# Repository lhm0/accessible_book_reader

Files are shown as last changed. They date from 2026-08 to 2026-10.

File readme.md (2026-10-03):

# Accessible Book Reader

## update October 3rd, 2026

The design files (`.f3z` / `.f3d`) and corresponding STL files for `front`,
`front2`, `back`, `back2`, and their `_dev` variants have been updated to
correct a design error.

The `camera_block` has also been redesigned for easier, higher-quality
printing. It now consists of two parts joined with a single screw.

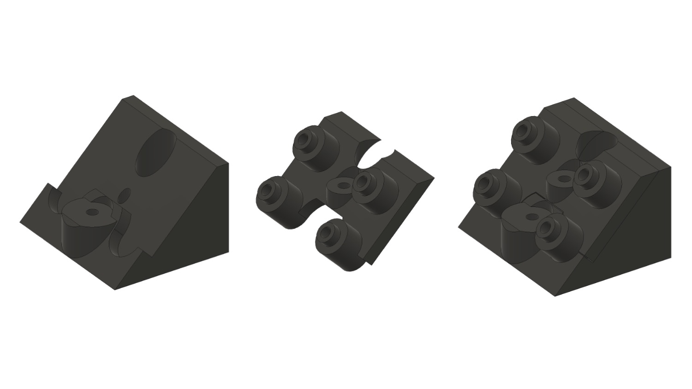
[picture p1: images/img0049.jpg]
Updated two-part camera block


## Project overview

**Listen to printed books – and catch up on the story at the press of a button.**

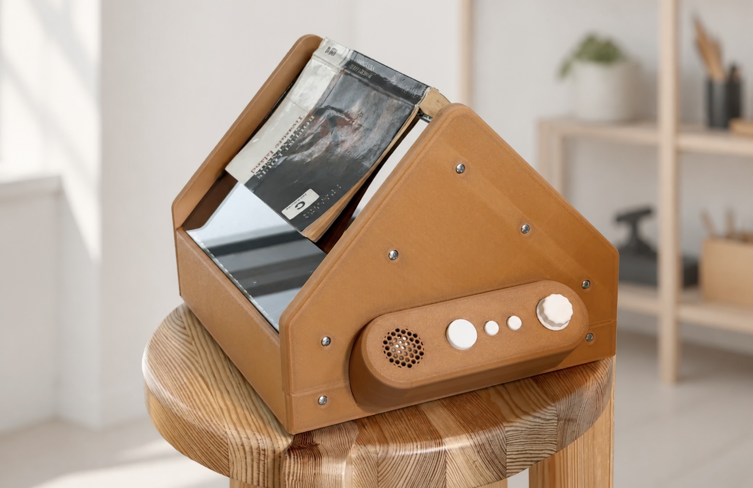
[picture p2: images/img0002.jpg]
Accessible Book Reader with a book in place, a speaker, three buttons and a volume knob


The **Accessible Book Reader (ABR)** is a reading device built around the
Raspberry Pi 5. It aims to make books more accessible to people who find
printed text difficult to read. Place an open book on the device, press a
button and listen: two cameras capture the spread, the device recognises
the text and reads both pages aloud in order. A sound signals when it is
time to turn the page by hand.

After a break, ABR can help you find your place in the story. At the press
of a button, it summarises the most recently captured sections or the book
so far. NFC tags identify each book and link it to its saved text and
summaries. Three buttons, a volume knob and spoken prompts provide the
on-device controls.

ABR combines a custom enclosure and electronics with open-source software.
This repository contains the code, circuit schematics, mechanical design
files and documentation for building and improving the device. Book-language
profiles for German and U.S. English are integrated. Text recognition runs
locally on the Raspberry Pi; the current speech and AI summary features use
Google Cloud services and require an internet connection and a configured
cloud account.

The physical device has been tested and is under active development.
Current work focuses on long-term testing and refining summaries.
Book identification currently uses a modified PN5180 NFC reader breakout
board; the setup is documented in this repository. A custom NFC reader is
also being developed to make the hardware easier to reproduce.
Feedback from users, build experiences and contributions are welcome.

[Deutsche Dokumentation](readme_DE.md) ·
[Installation](#installation) ·
[Hardware](hardware/README.md) ·
[Contributing](CONTRIBUTING.md) ·
[Licence](#licence)

## Development status

The project has progressed beyond a basic OCR/TTS prototype:

- the real capture path with two Raspberry Pi cameras has been verified
- `RapidOCR` runs reliably on the Raspberry Pi
- `Google Cloud TTS` is integrated
- the control panel, NFC book context, page storage, and automatic reading are implemented
- remote file maintenance by e-mail is implemented
- multiple saved Wi-Fi profiles can be selected automatically or switched explicitly
- central German and U.S. English book-language profiles control runtime TTS,
  chapter announcements, and RapidOCR model selection; German remains the
  backwards-compatible default
- new NFC books store their language permanently in `book.json`; OCR, ingest,
  chapter assembly, summaries, and TTS reject mixed-language book data

Current development focuses on:

- stabilising and refining the section and summary layer
- long-term testing of the integrated dual-reader PN5180 path with
  `ISO14443A` and `ISO15693`

## Current production path

The preferred real-world setup on a Raspberry Pi 5 is:

- runtime: `hardware/control_panel_service.py`
- page TTS: `Google Cloud TTS`, using the voice from the active language profile
- system messages: pre-generated WAV files from the active language folder
  (`system_audio/messages/de/` or `system_audio/messages/en/`)
- book identification: PN5180 gateway over UART
- audio hardware: MAX98357A over I2S; the system-wide ALSA `default` device
  must address this card by its symbolic card name

The runtime currently behaves as follows:

- PN5180 polling starts immediately with `STATUS_START`
- both photographs are captured before `STATUS_FETCH` retrieves the book identity;
  NFC reader position is no longer used for page orientation
- an `ISO14443A` tag remains the preferred book key; a simultaneously detected
  `ISO15693` tag is stored as an alternative identifier, while a new book can
  also be created directly from a single `ISO15693` tag
- before the normal page OCR, RapidOCR detects three long text lines in the
  prepared left image and classifies them as upright or upside down
- an upside-down result swaps `case/left.jpg` and `case/right.jpg`
- each reliable result updates `library/<TAG_ID>/state/page_orientation.json`;
  text-poor or empty pages use that stored value instead of aborting
- `case/right.jpg` is then rotated by 180 degrees exactly once; OCR
  preprocessing performs no additional fixed page rotation
- both pages are captured completely before processing begins
- the left page is processed before the right page
- image preparation, OCR, `PageIngestor`, and TTS initially run only for the left page
- while the left page is already playing, the right page proceeds through
  image preparation, OCR, `PageIngestor`, and TTS
- after the right page has played completely, the language-specific
  `tatata.wav` signals that the user should turn the page; cancellation or an
  audio/TTS error suppresses this signal

## Implemented features

### Device runtime

- long-running front-panel monitor
- `Start / Stop / NFC` triggers the real
  `capture -> image preparation -> OCR -> page-ingest` path
- heartbeat while waiting for the first page audio
- interruptible page playback
- turn-page signal only after successful completion of the complete spread;
  it is not played when page audio is cancelled
- EC11 edge-interrupt volume control with a thread-safe target value; it also
  applies block by block while `bing.wav` or page audio is playing
- book-deletion dialogue using the three-button chord and the EC11 push button
- persistent per-book usage statistics for scanned pages, reading time, and
  both summary functions; daily e-mail reports cover 04:00 to 04:00, including
  days without device use

### Book and page data

- one directory per book under `library/<TAG_ID>/`
- alternative ISO15693 mappings under
  `library/<ISO14443A_TAG_ID>/iso15693_tag_ids.txt`
- persistent OCR orientation fallback under
  `library/<TAG_ID>/state/page_orientation.json`
- `BookStore`
- `PageIngestor`
- `ChapterAssembler` for 10-to-20-page sections with mid-page boundaries
- `SummaryManager` for Gemini section and whole-book summaries
- one `PageRecord` per page
- one `ChapterRecord` per section
- one `ScanRecord` per double-page scan
- automatic page playback based on `speak_text`

### Text cases handled explicitly

- a missing page number on only one side of an otherwise complete double-page
  report; provisional `page_1.json`/`page_2.json` files are replaced with the
  inferred four-digit filenames after the second page is available
- multiple chapter markers on one page
- heading-only pages such as `INTERMEZZO`
- incomplete sentence fragments across pages
- hyphenation across lines and across the left/right page boundary
- letter-spaced words such as `U E B E R S C H R I F T` are spoken without the spacing
- short all-uppercase headings are made readable in `speak_text` and marked as separate paragraphs
- German spoken text replaces `Dr.` with `Doktor` and `Notre-Dame` with
  `Notre Damm`; the source-faithful `clean_text` remains unchanged (stored
  pages receive these replacements only after another page ingest)
- short parenthesised OCR artefacts containing digits are not carried over as
  sentence fragments to the next page
- chapter announcements use cardinal numbers, for example `Kapitel zwei`
- clear SSML pauses before and after chapter announcements

Current sentence-fragment behaviour:

- the right-page tail fragment is also kept in
  `library/<TAG_ID>/state/pending_right_tail_fragment.json`
- without a page number, no fragment from an earlier scan is prepended;
  pending state is never a substitute for a known predecessor
- inconsistent numbering in a complete spread also blocks carryover and is
  persisted as `metadata.page_number_sequence_valid=false`, preventing those
  pages from becoming fragment sources for later scans
- known numbering gives priority to the stored right page with the
  exact preceding number. Successfully renumbered opening pages qualify again
- if the numbered predecessor is entirely absent, a complete, consecutively
  numbered spread may use the fragment from `pages/page_2.json`, provided it
  is an unnumbered right page from another scan. An existing predecessor with
  no fragment does not trigger this fallback. Single-page reports and unclear
  current numbering cannot use it either
- during incremental processing, playback of the numbered left page waits
  for the right page in this special case. Both pages are then played after
  checking the full spread; inconsistent numbering omits the external fragment
- if that placeholder is subsequently renumbered automatically, its fragment
  is not prepended a second time
- left-to-right carryover within the same capture remains intact because
  physical adjacency is known even without page numbers
- plausible but factually wrong OCR numbers cannot be identified by this
  numbering check alone. Existing stored spoken text is not cleaned retroactively

### Recovering an unnumbered opening spread

After storing a complete spread with consecutive page numbers, the ingestor
checks for both unnumbered `pages/page_1.json` and `pages/page_2.json`. If both
immediately preceding page slots are free, these placeholders receive those
numbers. For example, ingesting pages 7/8 renames the placeholders to
`0005.json` / `0006.json`, with internal IDs `page_0005` / `page_0006`.

The placeholders must be the left/right pages of the same earlier scan.
Single-page reports, nonconsecutive numbers, already numbered placeholders,
or either occupied destination prevent repair. Existing numbered pages are
never overwritten. Repair runs during ingest, not just on service startup.

The correction updates scan manifests, chapter page lists and ranges, chapter
boundaries including `next_start_boundary`, assembler state, and structured
page references in state and summary files. Chapter summary ranges are updated;
summary prose is not regenerated. Source OCR reports, `metadata.report_page_id`,
scan identity and page text are preserved. A tail fragment from the repaired
right page is carried into the current spoken text when applicable.

Repaired pages have `metadata.page_number_inferred=true`,
`page_number_inference="following_spread"`, and the triggering scan ID in
`page_number_inference_scan_id`. The service logs
`Vorherige Doppelseite nachnummeriert: left:5, right:6; gespeicherte Referenzen aktualisiert.`

## Section and summary layer

- sections are assembled from existing `PageRecord` objects after every ingest
- a section ends at the first detected chapter boundary within a 10-to-20-page window
- without a chapter marker, a section ends at the last complete paragraph on
  page 20 and the following boundary is stored persistently
- completed sections are stored under `library/<TAG_ID>/chapters/`
- Gemini creates a section summary when a new section is completed
- the chapter/last-pages summary button speaks the latest section summary,
  creates or refreshes it when needed, and provides an intro plus `bing` heartbeat
- if open text exists after the last completed section, the same action
  combines it with the stored summary into a temporary current recap; this is
  spoken but not stored
- before the first completed section, the available open text is summarised temporarily
- the whole-book summary button creates and speaks a current “previously in
  this book” recap in chapter order, also with an intro and `bing` heartbeat
- if no summary is available, the runtime plays `keine_zusammenfassung`

## Installation

This README is the entry point for a new installation. Detailed hardware setup
and the final verification checklist are covered by
[docs/RASPBERRY_PI_SETUP.md](docs/RASPBERRY_PI_SETUP.md).

### 1. Prepare the Raspberry Pi and clone the repository

Raspberry Pi OS Lite (64-bit) is recommended. After the first boot, update the
system and install the required packages:

```bash
sudo apt update
sudo apt full-upgrade -y
sudo apt install -y \
  git curl ca-certificates \
  build-essential pkg-config \
  python3 python3-venv python3-pip python3-dev \
  tesseract-ocr tesseract-ocr-deu \
  libgl1 libopenblas-dev \
  espeak-ng alsa-utils pulseaudio-utils \
  htop tmux

mkdir -p ~/src
git clone https://github.com/lhm0/accessible_book_reader.git ~/src/abr
cd ~/src/abr
```

The cameras, header UART, and MAX98357A additionally require the entries in
`/boot/firmware/config.txt` and `/etc/asound.conf` described in the Raspberry
Pi setup guide. The repository's `config.txt` is a reference for the verified
hardware and must not blindly replace an existing boot configuration. Reboot,
then verify the cameras, UART, and audio as documented.

Firmware and wiring for the preferred PN5180 gateway are documented in
[hardware/pn5180_gateway/README.md](hardware/pn5180_gateway/README.md). The
alternative PN532 path is documented in
[hardware/pn532_gateway/README.md](hardware/pn532_gateway/README.md).

### 2. Install the Python environment

Create a fresh environment with the normal `python3`, not PlatformIO's Python,
and do not copy a virtual environment from another computer:

```bash
cd ~/src/abr
python3 -m venv .venv
source .venv/bin/activate
python -m pip install --upgrade pip
python -m pip install -e ".[ocr-rapidocr,dev,tts-google]"
```

Optional OCR backends:

```bash
pip install ".[ocr-tesseract]"
pip install ".[ocr-paddle]"
```

### 3. Configure Google Cloud for TTS and summaries

The production service requires Application Default Credentials (`ADC`) for a
Google Cloud project with billing and the required APIs enabled. After
installing the Google Cloud CLI for Raspberry Pi OS:

```bash
gcloud services enable \
  texttospeech.googleapis.com \
  aiplatform.googleapis.com \
  --project YOUR_PROJECT_ID
gcloud auth application-default login
gcloud auth application-default set-quota-project YOUR_PROJECT_ID
gcloud config set project YOUR_PROJECT_ID
```

These commands store credentials outside the repository under
`~/.config/gcloud/`. Never copy credential files into the project. The systemd
installer sets `HOME` to the installing user's home directory so that the
service finds the same ADC data. A service account may alternatively be
provided through Google's documented ADC mechanism. See the Raspberry Pi
setup guide for details and test commands.

### 4. Configure the device and install services

Run installers from the repository with `sudo`. They derive the user, home
directory, repository location, and `.venv` from the current installation; no
fixed username or absolute project path is required.

```bash
cd ~/src/abr
sudo deploy/install_language_switch.sh
sudo deploy/install_control_panel_service.sh
```

This creates `~/.config/abr/device.json` with German as the default when the
file is missing and installs the production service. Select the book language
with `sudo abr-language de` or `sudo abr-language en`. See
[docs/LANGUAGE_PROFILES.md](docs/LANGUAGE_PROFILES.md).

Optional features:

```bash
# Install continuous recovery across saved Wi-Fi profiles
sudo deploy/install_wifi_autoconnect.sh

# First run: create mail.ini; edit it, then run the installer again
sudo deploy/install_remote_mail.sh
sudo deploy/install_remote_mail.sh

# Install only after mail.ini has been configured
sudo deploy/install_usage_statistics.sh
```

Wi-Fi credentials remain in NetworkManager. Add profiles interactively using
the commands in [docs/WIFI_PROFILES.md](docs/WIFI_PROFILES.md). E-mail setup is
described below and in
[docs/REMOTE_MAINTENANCE_EMAIL.md](docs/REMOTE_MAINTENANCE_EMAIL.md).

### Local and generated configuration files

| Path | Purpose and creation | Tracked? |
|---|---|---|
| `/boot/firmware/config.txt` | Camera, UART, and I2S configuration; edit according to the Pi setup guide | No |
| `/etc/asound.conf` | ALSA default for MAX98357A; edit according to the Pi setup guide | No |
| `~/.config/gcloud/` | Google ADC and quota project; generated by `gcloud` or a service-account setup | No |
| `~/.config/abr/device.json` | Book language; generated by `install_language_switch.sh` | No |
| `~/.config/abr/mail.ini` | Mail account and recipient; neutral template generated by `install_remote_mail.sh` | No |
| NetworkManager profiles | SSIDs and Wi-Fi passwords; created interactively with `abr.wifi_profiles` | No |
| `/etc/systemd/system/abr-*.service` and `abr-*.timer` | Local user and project paths; generated by the relevant service installers | No |
| `calibration/out/cam0_planar.npz`, `cam1_planar.npz` | Included reference calibration; regenerate for different camera mechanics | Yes |

No `.env` file is required. Optional experimental backends read
`OPENAI_API_KEY` or `ELEVENLABS_API_KEY` only from the local process
environment. The production Google path uses ADC.

### 5. Verify the installation

```bash
cd ~/src/abr
source .venv/bin/activate
python -m pytest -q
systemctl status abr-control-panel.service --no-pager -l
journalctl -u abr-control-panel.service -n 100 --no-pager
```

Then complete the hardware and runtime verification in
[docs/RASPBERRY_PI_SETUP.md](docs/RASPBERRY_PI_SETUP.md).

### Local e-mail configuration

Personal addresses, usernames, and passwords are not stored in the
repository. Mail features read `~/.config/abr/mail.ini` on the Raspberry Pi.
The first invocation of `sudo deploy/install_remote_mail.sh` creates a template
with mode `0600`. Edit the local file:

```ini
[mail]
address = abr-device@example.com
recipient = owner@example.com
username = abr-device@example.com
password = MAIL_APP_PASSWORD
smtp_host = smtp.example.com
smtp_port = 465
imap_host = imap.example.com
imap_port = 993
inbox = INBOX
```

`address` and `username` identify the device account. Remote-maintenance files
and usage reports are sent to `recipient`, and uploads are accepted only from
that exact sender. Real values remain exclusively in this local, untracked
file. For backwards compatibility, installations without `recipient` use the
value of `address`.

Important operational notes:

- `rapidocr` and `onnxruntime` are required for the primary OCR path
- Tesseract remains a fallback and comparison backend
- PaddleOCR is currently not a reliable production path on Raspberry Pi
- automatic summaries use the same Google Cloud credentials as TTS
- `target-pages` is converted at 250 words per text page; `0.5` therefore
  targets 125 words
- Gemini receives a generous technical token budget so internal thinking
  tokens do not truncate the visible answer prematurely
- if the first answer exceeds the word limit by more than ten percent, a
  separate shortening pass is performed
- only a response not terminated by the token limit is stored with
  `generation_complete=true`; legacy summaries without this marker are
  regenerated once on their next use
- `/etc/asound.conf` must expose a `plug` PCM named `default` for
  `hw:CARD=MAX98357A,DEV=0`; otherwise `aplay` may open HDMI and fail with
  `Unknown error 524`

## Quick start

### Manual capture and OCR reference run

```bash
cd ~/src/abr
source .venv/bin/activate
python hardware/capture_double_page.py --no-denoise
python hardware/run_rapidocr.py \
  --ocr-dir captures/latest/ocr \
  --output-dir runs/latest_rapidocr \
  --orientation-mode off \
  --overlay
```

### Full runtime service on the Raspberry Pi

The runtime may be started directly for short manual tests. Continuous
operation uses the SSH-independent `abr-control-panel.service`; installation,
logs, restart testing, and troubleshooting are documented in
[docs/SYSTEMD_CONTROL_PANEL_SERVICE.md](docs/SYSTEMD_CONTROL_PANEL_SERVICE.md).

```bash
cd ~/src/abr
source .venv/bin/activate
python hardware/control_panel_service.py \
  --gpio-backend auto \
  --job-mode capture-ocr \
  --library-root library \
  --nfc-mode gateway \
  --page-tts-speed 0.85 \
  --chapter-summary-target-pages 1.5 \
  --book-summary-target-pages 1.5
```

### Separate Neural2-H test

The production Google path remains unchanged: backend `google`, voice
`de-DE-Standard-H`, and still the default when no additional option is given.
Neural2-H is an isolated opt-in path:

```bash
python hardware/control_panel_service.py \
  --gpio-backend auto \
  --job-mode capture-ocr \
  --library-root library \
  --nfc-mode gateway \
  --page-tts-backend google-neural2 \
  --page-tts-speed 0.85
```

Return to the production path with `--page-tts-backend google` or omit the
option. `--google-neural2-voice-name` selects a different Neural2 voice; the
default is `de-DE-Neural2-H`.

### Standard-H with enhanced SSML preparation

The optional `google-standard-enhanced` path still uses `de-DE-Standard-H` and
the same Google Cloud TTS backend. Only text preparation differs: paragraphs
and sentences are structured, chapters retain their long pause, and short
headings are moderately emphasised and separated from following text. For
questions, the complete final word is experimentally raised by `+3st`. The
renderer verifies that no spoken words were changed and falls back to the
original SSML preparation if validation fails.

Sentences inside a paragraph receive a `900ms` pause. The last sentence of a
paragraph receives `2000ms` instead; pauses are not added together. Paragraph
boundaries come from OCR `layout_blocks` and are stored as blank lines in
`speak_text`. For already stored pages, a simple line break after `.` or `?`
also acts as a fallback paragraph boundary, including a directly following
closing quotation mark. If a fully quoted dialogue sentence in `"..."`,
`»...«`, or `„...“` is followed by a paragraph break, that boundary is spoken
like a normal sentence boundary: `900ms` instead of `2000ms`. Stored paragraph
data is not changed.

Enable the path with:

```bash
python hardware/control_panel_service.py \
  --gpio-backend auto \
  --job-mode capture-ocr \
  --library-root library \
  --nfc-mode gateway \
  --page-tts-backend google-standard-enhanced \
  --page-tts-speed 0.9
```

The unchanged Standard-H path remains available through
`--page-tts-backend google` or by omitting the option.

### Page direction and repeated-page checks

The runtime stores, per book, the page numbers of the most recently accepted
double-page scan:

- if a new scan overlaps those page numbers, it plays
  `system_audio/messages/<language>/repeat_page.wav` and cancels page playback
- if the smallest new page number is below the smallest previously read page,
  it plays `system_audio/messages/<language>/wrong_direction.wav` and cancels playback
- the immediately following scan may pass the condition once; the relevant
  override marker is then cleared
- if the right-side partial result arrives after a warning from the same scan,
  it is not played either
- scans without detected page numbers bypass these two checks

Markers and last-read pages are maintained per book and removed when the book
is deleted. These warnings play directly in the ingest path rather than via
the general asynchronous system-audio queue. The runtime logs their start and
successful completion and reports a missing WAV path explicitly. In the
incremental capture path, the runner waits for the left ingest result; if it
triggers a warning, the foreground job stops before right-side preparation and
OCR. After the warning, the normal `CANCELLED` event returns the runtime to
`IDLE`.

### Long summaries

Before Google TTS, chapter and whole-book summaries are split at complete
sentences when the rendered input would otherwise be too large. Summary chunks
are limited to 900 bytes including SSML; the general Google safety limit is
3800 bytes. Chunks use the same audio queue and play in order, with labels such
as `1/N` and `2/N`. Short summaries remain a single TTS request.

The pre-generated summary announcement and first `bing` play synchronously
before the summary job. Pending heartbeat sounds are discarded after summary
audio is activated, preventing a late `bing` after the summary.

The validity of `book_so_far_summary.json` includes a SHA-256 fingerprint of
the content and modification time of every chapter summary. A previous short
book summary is regenerated when its sources change. Legacy files without a
fingerprint are refreshed once on their next use.

Chapter and book summaries follow the active language profile. German uses
German prompts; English uses U.S. English prompts. Persistent summary files
store `metadata.language`. A cache in another language is regenerated, while
legacy cache files without a language field are treated as German.

### Separate Gemini 2.5 Flash TTS test

Gemini TTS is another isolated opt-in path:

```bash
python hardware/control_panel_service.py \
  --gpio-backend auto \
  --job-mode capture-ocr \
  --library-root library \
  --nfc-mode gateway \
  --page-tts-backend google-gemini-flash \
  --page-tts-speed 0.85
```

Defaults for this experimental path:

- model `gemini-2.5-flash-tts`
- voice `Charon`
- a dedicated German audiobook prompt
- plain-text rather than SSML input; the prompt controls pauses and delivery

Optional overrides:

```bash
--google-gemini-flash-voice-name Charon
--google-gemini-flash-prompt "Lies ruhig und natuerlich wie ein Hoerbuchsprecher."
```

Google limits both Gemini TTS text and prompt to 4000 bytes. The backend checks
this limit and reports a clear error instead of silently truncating input.
Return to the production path with `--page-tts-backend google` or omit the
option.

### Offline ingest of an existing OCR report

```bash
cd ~/src/abr
source .venv/bin/activate
python hardware/page_ingest_debug.py \
  --library-root library \
  --book-tag-id TESTBOOK \
  --report-path captures/scan_xxx/ocr_text/report.json
```

## Generate system messages

Tool: [hardware/generate_audio_message.py](hardware/generate_audio_message.py)

```bash
python hardware/generate_audio_message.py \
  --ssml \
  --output-root ~/tmp_audio_export/de \
  fehler \
  '<speak>Fehler.<break time="700ms"/>Bitte erneut versuchen.</speak>'
```

Generate new messages outside the repository on the Raspberry Pi. Copy them
to the Mac afterwards and only then place them in the relevant
`system_audio/messages/de/` or `system_audio/messages/en/` directory.

## Important documentation

- [German README](readme_DE.md)
- [docs/LANGUAGE_PROFILES.md](docs/LANGUAGE_PROFILES.md)
- [docs/CONTROL_RUNTIME_ARCHITECTURE.md](docs/CONTROL_RUNTIME_ARCHITECTURE.md)
- [docs/BOOK_RUNTIME_DATA_ARCHITECTURE.md](docs/BOOK_RUNTIME_DATA_ARCHITECTURE.md)
- [docs/SOFTWARE_STRUCTURE.md](docs/SOFTWARE_STRUCTURE.md)
- [docs/WIFI_PROFILES.md](docs/WIFI_PROFILES.md)
- [docs/REMOTE_MAINTENANCE_EMAIL.md](docs/REMOTE_MAINTENANCE_EMAIL.md)
- [hardware/README.md](hardware/README.md)

## Licence

The Accessible Book Reader is an open-source and open-hardware project with
strong copyleft. Different kinds of project material use a clearly separated
multi-licence model:

- original software and firmware: `GPL-3.0-or-later`
- original electronics, mechanics, and other hardware designs:
  `CERN-OHL-S-2.0`
- documentation and clearly identified original media: `CC-BY-SA-4.0`
- third-party libraries: their respective original licences

The system messages generated with Google Cloud Text-to-Speech have a
dedicated [provenance and usage notice](system_audio/messages/README.md).

GPL and CERN-OHL-S permit commercial use, but distribution of derived
software or hardware requires the corresponding complete source material to
be made available under the applicable copyleft terms. There is no general
exception for closed commercial derivatives.

The binding scope, third-party exceptions, and exclusions are documented in
[LICENSE.md](LICENSE.md). Full licence texts are stored in [`LICENSES/`](LICENSES/),
and bundled third-party components are documented in
[THIRD_PARTY_NOTICES.md](THIRD_PARTY_NOTICES.md). Contributions are governed
by [CONTRIBUTING.md](CONTRIBUTING.md) and the
[Contributor License Agreement](CLA.md). Contributors retain ownership while
granting the project owner the additional right to offer parallel commercial
licences for future business cooperation. Any cooperation that departs from
the public licences requires a separate development and licence agreement
with the relevant rights holders.

No patent or freedom-to-operate search has been performed. The licences can
grant only rights controlled by the respective licensor and do not warrant
that making, using, or distributing the project is free from third-party
rights. See [PATENT_NOTICE.md](PATENT_NOTICE.md), in particular for the
distinction between private builds and commercial use.

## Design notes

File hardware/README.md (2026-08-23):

# Hardware Uebersicht

Dieses Verzeichnis enthaelt die hardwarebezogenen Teilprojekte fuer den
aktuellen ABR-Scannerstand.

## Struktur

- [pn532_gateway](../hardware/pn532_gateway/README.md)
  - RP2040-/Pico-Gateway fuer `2 x PN532`
  - UART-Protokoll zum `Raspberry Pi 5`
  - weiterhin als alternativer NFC-Pfad im Repo

- [pn5180_gateway](../hardware/pn5180_gateway/README.md)
  - RP2040-/Pico-Gateway fuer bis zu `2 x PN5180`
  - aktueller produktiver Buchkennungs-Pfad
  - aktueller technischer Arbeitsstand: `2 x PN5180`, sequentielle
    Reader-Freigabe ueber `RESET`, on-demand statt Polling

- [electronics](../hardware/electronics/README.md)
  - KiCad-Projekte fuer Pi-Header, Bedienpanel und LED-Bar

- [mechanics](../hardware/mechanics/README.md)
  - Fusion- und Exportdateien fuer den Scanneraufbau

## Wichtige Pi-Skripte

- [capture_double_page.py](../hardware/capture_double_page.py)
  - produktionsnaher Zwei-Kamera-Capture
  - schaltet `LED-left` und `LED-right` passend zur Aufnahme
  - erzeugt `raw`, `rectified`, `case`, `ocr` und `debug/page_1..2`
  - `--no-denoise` ist aktuell der bevorzugte schnelle Pfad

- [run_rapidocr.py](../hardware/run_rapidocr.py)
  - schlanker RapidOCR-Wrapper fuer vorbereitete `ocr/left.png` und
    `ocr/right.png`
  - schreibt `left.txt`, `right.txt` und `report.json`
  - bevorzugter Standard: `--orientation-mode off`

- [camera_test_server.py](../hardware/camera_test_server.py)
  - Browser-Livebildtest fuer die Pi-Kameras
  - optionales Fadenkreuz
  - Review-Modus fuer `raw`, `rectified`, `enhanced` und `ocr-overlay`

- [led_light_test.py](../hardware/led_light_test.py)
  - einfacher Test fuer `LED-left` auf `BCM12` und `LED-right` auf `BCM13`

- [control_panel_test.py](../hardware/control_panel_test.py)
  - einfacher GPIO-Test fuer Taster und `EC11`

- [control_panel_service.py](../hardware/control_panel_service.py)
  - aktueller produktionsnaher Runtime-Dienst
  - startet den echten Lauf `capture -> Bildvorbereitung -> OCR -> page-ingest`
  - liest Buch-Tags ueber NFC-Gateway
  - startet die PN5180-Abfrage beim Tastendruck mit `STATUS_START` und holt
    sie nach beiden Aufnahmen mit `STATUS_FETCH` ab
  - verwendet ISO14443A als fuehrende Buch-ID und ISO15693 als gespeicherte
    alternative Zuordnung
  - ordnet die Kamerabilder anhand des ISO14443A-Readers zu:
    Orientierung 1 behaelt links/rechts, Orientierung 2 vertauscht beide
  - dreht danach `case/right.jpg` einmalig um 180 Grad
  - speichert Ergebnisse unter `library/<tag_id>/`
  - nimmt beide Seiten zuerst komplett auf
  - verarbeitet danach links vor rechts
  - startet die Seitenausgabe, sobald die linke Seite als Audio vorliegt
  - zieht die rechte Seite waehrend der linken Wiedergabe nach
  - spielt nach vollstaendig beendeter rechter Seitenausgabe `tatata.wav` als
    Umblättersignal; Stop, TTS-Fehler und Wiedergabefehler unterdruecken es
  - spielt vor dem Start `bing`
  - spielt waehrend des Wartens einen Heartbeat mit erneutem `bing`
  - beendet den Heartbeat sauber bei Erfolg, Stop oder Fehler
  - spielt bei nicht vorlesbarem Ingest-Ergebnis `fehler`
  - stoppt eine laufende Seitenausgabe per `Start / Stop`
  - unterstuetzt den Buch-Loeschdialog per Dreifachtaste
  - erzeugt neue Abschnittszusammenfassungen direkt nach neuer
    Abschnittsbildung
  - spielt bei den beiden Summary-Tasten zuerst
    `kapitel_zusammenfassen` bzw. `buch_zusammenfassen`
  - startet danach einen `bing`-Heartbeat bis die Summary-Audio bereit ist
  - spielt `keine_zusammenfassung`, wenn noch kein passender Summary-Text
    verfuegbar ist
  - unterstuetzt konfigurierbares Artefakt-Cleanup

- [page_ingest_debug.py](../hardware/page_ingest_debug.py)
  - Offline-Debugpfad fuer `report.json -> PageRecord -> BookStore`

- [generate_audio_message.py](../hardware/generate_audio_message.py)
  - erzeugt vorproduzierte Audio-Botschaften fuer Systemhinweise
  - Standardstimme: `Google Cloud TTS`, `de-DE-Standard-A`
  - Standardpfad: `system_audio/messages`
  - `--ssml` erlaubt `<break .../>`
  - fuer Raspi-only-Erzeugung ohne Git-Konflikte sollte `--output-root`
    ausserhalb des Repo-Pfads verwendet werden

## Aktueller Runtime-Pfad

Die aktuelle Pi-Laufzeit besteht aus:

1. GPIO-Flankeninterrupts fuer EC11 A/B und Taster-Polling ueber
   `FrontPanelMonitor`; `pinctrl` bleibt Encoder-Polling-Fallback
2. Action-Routing zu fachlichen Aktionen
3. `RuntimeController`
4. `ForegroundJobManager` fuer `capture -> Bildvorbereitung -> OCR -> page-ingest`
5. `PageIngestService`
6. `PageAudioPlayer`
7. `SystemAudio` fuer Warnhinweise

Die EC11-Interruptbehandlung aktualisiert nur einen threadsicheren
Lautstaerke-Sollwert. Seiten- und Systemaudio fragen ihn waehrend der
Wiedergabe blockweise ab. Der dynamische `aplay`-Pfad arbeitet mit `250ms`
PCM-Vorlauf, `300ms` ALSA-Puffer und `50ms` Perioden; jeder PCM-Block wird
sofort geflusht. Damit bleibt insbesondere `bing.wav` trotz laufender
Lautstaerkeregelung zusammenhaengend.

Produktiv verdrahtet sind jetzt zusaetzlich:

- `Buch-Zusammenfassung`
- `Kapitel-/Letzte-Seiten-Zusammenfassung`
- `ChapterAssembler`
- `SummaryManager`

Pi-Audio-Voraussetzung:

- `/etc/asound.conf` definiert das globale ALSA-`default` als `plug`-PCM fuer
  `hw:CARD=MAX98357A,DEV=0`
- der symbolische Kartenname ist verbindlich; numerische Kartenindizes koennen
  durch die beiden HDMI-Karten wechseln
- Setup, Referenztests und Fehlerbild `Unknown error 524` stehen in
  [docs/RASPBERRY_PI_SETUP.md](../docs/RASPBERRY_PI_SETUP.md)

Wichtig:

- `SummaryService` existiert weiterhin als allgemeine asynchrone
  Hilfskomponente im Repo
- der produktive `control_panel_service` verwendet aktuell aber direkt den
  `SummaryManager`

## Pi-Referenzkommando

Dieses Kommando dient dem manuellen Test. Fuer den Dauerbetrieb wird
`abr-control-panel.service` verwendet. Die vollstaendige Einrichtung und
Diagnose steht in
[docs/SYSTEMD_CONTROL_PANEL_SERVICE.md](../docs/SYSTEMD_CONTROL_PANEL_SERVICE.md).

```bash
cd ~/src/abr
source .venv/bin/activate
python hardware/control_panel_service.py \
  --gpio-backend auto \
  --job-mode capture-ocr \
  --library-root library \
  --nfc-mode gateway \
  --page-tts-speed 0.85 \
  --chapter-summary-target-pages 1.5 \
  --book-summary-target-pages 1.5
```

Nuetzliche Optionen:

- `--artifact-mode debug|production`
- `--cleanup-stage after-ocr|after-ingest`
- `--page-tts-backend google|google-standard-enhanced|google-neural2|google-gemini-flash`
- `--page-tts-speed 0.9`
- `--volume-mixer-control auto`
- `--summary-gemini-model gemini-3.5-flash`
- `--summary-gcp-project <PROJECT_ID>`
- `--summary-gcp-location global`
- `--chapter-summary-target-pages 1.5`
- `--book-summary-target-pages 1.5`

Bei beiden Summary-Parametern entspricht eine Zielseite `250` Woertern.
Beispielsweise erzeugt `0.5` eine Zielgrenze von `125` Woertern. Wird diese
Grenze um mehr als zehn Prozent ueberschritten, kuerzt Gemini das Ergebnis in
einem zweiten Durchlauf.

Die Taste `Kapitel-/Letzte-Seiten-Zusammenfassung` beruecksichtigt auch Text,
der nach dem letzten abgeschlossenen Abschnitt aufgenommen wurde. Der
`ChapterAssembler` liest ihn ab seiner persistenten offenen Abschnittsgrenze.
Gemini verbindet ihn mit der gespeicherten Zusammenfassung des letzten
Abschnitts. Diese aktuelle Zwischenzusammenfassung wird nur vorgelesen und
nicht unter `summaries/` gespeichert. Existiert noch kein fertiger Abschnitt,
wird der bisherige offene Text allein temporaer zusammengefasst.

Zur Seitensprache:

- `google` bleibt der unveraenderte Default mit `de-DE-Standard-H`
- `google-standard-enhanced` verwendet dieselbe Standard-H-Stimme und
  dasselbe Backend, strukturiert den Text aber mit SSML fuer Saetze,
  Absaetze und Ueberschriften; bei Fragen wird das vollstaendige letzte Wort
  um drei Halbtoene angehoben; nach Saetzen innerhalb eines Absatzes liegen
  `900ms`, nach dem letzten Satz eines Absatzes stattdessen `2000ms` Pause.
  Als Absatz gilt auch ein einfacher Zeilenumbruch nach `.` oder `?`,
  optional gefolgt von einem schliessenden Anfuehrungszeichen. Direkt nach
  einem vollstaendig eingerahmten Dialogsatz gilt trotz Absatzwechsel nur die
  Satzpause von `900ms`.
- `google-neural2` ist ein separater Versuchsweg mit
  `de-DE-Neural2-H`
- `google-gemini-flash` ist ein separater promptgesteuerter Versuchsweg mit
  `gemini-2.5-flash-tts` und der Stimme `Charon`
- Weglassen von `--page-tts-backend` oder explizites
  `--page-tts-backend google` stellt jederzeit den bisherigen Pfad her

Zur Seitenfolge:

- die Runtime merkt sich pro Buch die beiden zuletzt zur Ausgabe
  angenommenen Seitenzahlen
- eine unmittelbar wiederholte Seite fuehrt zu `repeat_page.wav`
- eine niedrigere Doppelseite fuehrt zu `wrong_direction.wav`
- die jeweilige Warnung kann mit einem erneuten Scan einmal bestaetigt
  werden; das spaeter eintreffende zweite Teilergebnis des abgewiesenen
  Scans bleibt unterdrueckt

Zur Summary-Laenge:

- `target-pages` wird mit `250` Woertern pro Zielseite in eine konkrete
  Wortgrenze umgesetzt
- ein grosszuegiges technisches Tokenbudget verhindert, dass Thinking die
  sichtbare Antwort vorzeitig abschneidet
- bei mehr als zehn Prozent Ueberschreitung folgt ein Kuerzungsdurchlauf

## Weitere Doku

- [docs/HARDWARE_GPIO_PLAN.md](../docs/HARDWARE_GPIO_PLAN.md)
- [docs/CONTROL_PANEL_ARCHITECTURE.md](../docs/CONTROL_PANEL_ARCHITECTURE.md)
- [docs/CONTROL_RUNTIME_ARCHITECTURE.md](../docs/CONTROL_RUNTIME_ARCHITECTURE.md)
- [docs/BOOK_RUNTIME_DATA_ARCHITECTURE.md](../docs/BOOK_RUNTIME_DATA_ARCHITECTURE.md)
- [docs/DOUBLE_PAGE_CAPTURE.md](../docs/DOUBLE_PAGE_CAPTURE.md)

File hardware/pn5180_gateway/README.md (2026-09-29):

# PN5180 Pico Gateway

Dieses Unterprojekt ist der aktuelle PN5180-NFC-Gateway-Pfad fuer `abr`:

- ein Raspberry Pi Pico als Gateway
- bis zu zwei PN5180-Reader am gemeinsamen `SPI0`-Bus des Pico
- ein Raspberry Pi 5, der den Pico unveraendert per UART abfragt

Die Host-Schnittstelle zum Raspberry Pi bleibt bewusst dieselbe wie beim
`pn532_gateway`:

- gleiche ASCII-Kommandos
- gleiche `PING`-/`STATUS`-/`REINIT`-/`DIAG`-Struktur
- gleiche UART-Baudrate `115200`

Der aktuelle Firmware-Stand am `2026-07-30` ist auf den realen
Zwei-Reader-Aufbau mit Relaisumschaltung abgestimmt:

- `PN5180 #1` und `PN5180 #2` sind aktiv
- beide Reader teilen sich weiterhin denselben `SPI0`-Bus
- beide Reader werden aber nie gleichzeitig freigegeben
- im Leerlauf bleiben beide PN5180 in `RESET`
- ein Reader wird nur fuer einen expliziten Befehl kurz freigegeben
- die Freigabe erfolgt strikt nacheinander, so dass immer nur ein
  Antennen-/Relaispfad aktiv ist
- die Statuslogik prueft aktuell wieder `ISO14443A` und `ISO15693`
- der feste Default fuer `RX_WAIT_CONFIG` ist `0x00000878`

## Konzept

Die Architektur ist:

- UART zwischen Pico und RP5 ueber `GP0/GP1` bzw. `GPIO15/GPIO14`
- gemeinsamer `SPI0`-Bus auf dem Pico fuer beide PN5180
- pro PN5180 eigene Leitungen fuer:
  - `NSS`
  - `BUSY`
  - `RESET`
  - `IRQ`
- kein permanentes Reader-Polling
- textbasierte Statusabfrage vom Raspberry Pi

Der normale Firmware-Stand verwendet aktuell fuer `STATUS`
einen on-demand-Lesepfad:

- harter Reader-Reset
- RF-Neuaufbau
- zuerst `ISO14443A`
- danach `ISO15693`
- danach Rueckkehr in `RESET`

Bei fruehen Reader- oder Kommunikationsfehlern wird derselbe Status-Probe
mehrfach wiederholt, bevor die Firmware aufgibt.

## Firmware

- PlatformIO-Environment: `pico`
- Quelle: [src/pico_gateway.cpp](../../hardware/pn5180_gateway/src/pico_gateway.cpp)

Build:

```bash
pio run -e pico
```

Die erzeugte UF2-Datei liegt danach unter:

```bash
.pio/build/pico/firmware.uf2
```

## Verdrahtung

### UART zum Raspberry Pi 5

Pico:

- `GP0` = TX zum RP5
- `GP1` = RX vom RP5
- `GND` gemeinsam

RP5:

- `GPIO15 / RXD` <- Pico `GP0 / TX`
- `GPIO14 / TXD` -> Pico `GP1 / RX`
- `GND` gemeinsam

Wichtig: nur `3,3 V`-Pegel verwenden.

### Gemeinsamer SPI0-Bus

- `GP16` -> `MISO`
- `GP18` -> `SCK`
- `GP19` -> `MOSI`
- `3V3` -> `VCC`
- `GND` -> `GND`

### PN5180 #1

- `GP2` -> `NSS`
- `GP3` <- `BUSY`
- `GP4` -> `RESET`
- `GP5` <- `IRQ`

### PN5180 #2

- `GP6` -> `NSS`
- `GP7` <- `BUSY`
- `GP8` -> `RESET`
- `GP9` <- `IRQ`

### Nicht Verwendete Breakout-Pins

Die typischen zusaetzlichen Breakout-Signale wie `GPIO`, `AUX` oder `REQ`
werden fuer diesen Gateway-Stand nicht benoetigt.

## Pinwahl Am Pico

Die Belegung ist bewusst so gewaehlt:

- `GP0/GP1` bleiben exklusiv fuer den UART-Pfad zum Pi reserviert
- `GP2..GP9` bilden zwei leicht merkbare Reader-Gruppen
- `SPI0` bleibt auf der Standardbelegung `GP16/GP18/GP19`
- damit ist keine Sonderkonfiguration eines alternativen SPI-Routings noetig
- `GP10..GP15` und `GP17` bleiben als Reserve frei

## UART Protokoll

Der Pico akzeptiert zeilenbasierte ASCII-Kommandos mit Newline.

Befehle:

- `PING`
- `STATUS`
- `STATUS 1`
- `STATUS 2`
- `STATUS_START`
- `STATUS_START 1`
- `STATUS_START 2`
- `STATUS_FETCH`
- `REINIT`
- `REINIT 1`
- `REINIT 2`
- `DIAG`
- `TYPEA_DIAG`
- `TYPEA_TUNE`
- `TYPEA_TUNE 1`
- `TYPEA_TUNE 1 RXWAIT 0x00000878`
- `TYPEA_SWEEP`
- `TYPEA_SWEEP 1`
- `TYPEA_SWEEP 1 20`
- `HELP`

Hinweise:

- `STATUS` ist synchron und liefert das Ergebnis direkt
- `STATUS_START` startet die Statusermittlung asynchron und kehrt sofort zurueck
- `STATUS_FETCH` holt das zuletzt angestossene Ergebnis ab und wartet bei
  Bedarf bis zum Abschluss
- `TYPEA_DIAG` fuehrt denselben Pfad explizit fuer `REQA` und `WUPA` mit
  Detailausgabe aus
- `TYPEA_SWEEP` testet mehrere `RXWAIT`-Werte nacheinander und kann deutlich
  laenger laufen als ein normaler `STATUS`

Beispielantwort auf `STATUS`:

```text
OK uptime_ms=12345
READER id=1 label=PN5180-1 enabled=1 online=1 fw=0x04000400 tag=1 uid=53:33:B1:6D:22:00:01 tech=ISO14443A len=7 agc=99 rf_status=0x00060063 rx_status=0x00000001 rx_len=1 tag15693=0 uid15693=- len15693=- tag14443a=1 uid14443a=53:33:B1:6D:22:00:01 len14443a=7 last_error=none
READER id=2 label=PN5180-2 enabled=1 online=1 fw=0x04000400 tag=1 uid=E0:04:01:09:16:F0:5F:A7 tech=ISO15693 len=8 agc=152 rf_status=0x01060098 rx_status=0x0000000A rx_len=10 tag15693=1 uid15693=E0:04:01:09:16:F0:5F:A7 len15693=8 tag14443a=0 uid14443a=- len14443a=- last_error=none
END
```

Hinweise zur PN5180-spezifischen Bedeutung:

- `fw` packt `product_major`, `product_minor`, `firmware_major`, `firmware_minor`
  in ein `uint32`-Hexfeld
- `agc` ist der aktuelle `RF_STATUS.AGC_VALUE` des PN5180
- `rf_status` ist der komplette rohe Registerwert `RF_STATUS`
- `rx_status` ist der komplette rohe Registerwert `RX_STATUS`
- `rx_len` ist die aus `RX_STATUS[8:0]` abgeleitete empfangene Nutzdatenlaenge

Wichtig:

- `tech` zeigt den bevorzugten Snapshot des Readers
- wenn sowohl `ISO14443A` als auch `ISO15693` gefunden werden, sind die
  protokollspezifischen Felder massgeblich
- `RX_STATUS` ist fuer die weitere Bewertung der Empfangsqualitaet oft
  aussagekraeftiger als die intern geregelte AGC-Groesse allein
- `TYPEA_TUNE` zeigt im Normalfall `override_rxwait=off`; das ist korrekt, weil
  `0x00000878` als fester Default in der Firmware hinterlegt ist

## Flashen

Die Datei `.pio/build/pico/firmware.uf2` auf den Pico im Bootloader-Modus kopieren.

Serieller Monitor waehrend der Entwicklung:

```bash
pio device monitor -b 115200
```

Die Firmware wartet beim Boot aktuell etwa `3 s`, bevor die ersten
USB-Debugmeldungen gesendet werden. Das soll sicherstellen, dass ein frisch
geoeffneter Monitor die Startmeldungen zuverlaessiger sieht.

Wichtig: Die UART-Schnittstelle zum Raspberry Pi wird dabei bereits sofort
aktiviert und waehrend dieser Wartezeit schon bedient. `PING`, `STATUS` und
`STATUS_START` muessen also auch waehrend des Startfensters antworten.

Zusätzlich setzt die Firmware den Pico-UART etwa `1 s` nach dem Boot einmal
gezielt neu auf und leert den RX-Puffer. Das soll Stoerzeichen oder
Fragmentbytes aus der gemeinsamen Einschaltphase zwischen `RP5` und `Pico`
abraeumen.

Zusätzlich wartet der normale Firmware-Stand nach dem Einschalten noch einige
Sekunden, bevor die PN5180-Initialisierung startet. Dadurch wird ein kalter
Gesamtstart robuster, wenn `Raspberry Pi 5`, `Pico` und Reader gleichzeitig
hochfahren und die Versorgung bzw. das Reader-Startup noch nicht stabil sind.

Im aktuellen on-demand-Stand bleiben die PN5180 auch nach der Startphase im
Leerlauf in `RESET` und werden erst fuer einen konkreten Readerzugriff
freigegeben.

Im Normalbetrieb ist das USB-Log jetzt bewusst knapp:

- Bootmeldungen
- `Tag erkannt` inklusive `UID`, `AGC`, `RF_STATUS` und `RX_STATUS`
- `Tag entfernt` inklusive letzter `UID`, `AGC`, `RF_STATUS` und `RX_STATUS`
- bei `Return` im USB-Seriellmonitor: aktuelle Statusausgabe pro Reader
  inklusive `UID`, `Tech`, `Len`, `AGC`, `RF_STATUS` und `RX_STATUS`
- per USB steuerbare `TYPEA`-Diagnose
- per USB steuerbarer `RXWAIT`-Sweep
- per USB steuerbarer Signal-Scan und RF-Profil-Scan fuer weitere Margin-Tests

USB-Befehle:

- `HELP`
- `STATUS`
- `STATUS_START`
- `STATUS_START 1`
- `STATUS_START 2`
- `STATUS_FETCH`
- `TYPEA_DIAG`
- `TYPEA_TUNE`
- `TYPEA_TUNE 1`
- `TYPEA_TUNE 1 RXWAIT 0x00000878`
- `TYPEA_SWEEP`
- `TYPEA_SWEEP 1`
- `TYPEA_SWEEP 1 20`
- `SCAN`
- `SCAN 1`
- `SCAN 1 16`
- `PROFILESCAN`
- `PROFILESCAN 1`
- `PROFILESCAN 1 8`

Optional kann die Pico-Onboard-LED einen Heartbeat anzeigen. Standardmaessig
ist diese Debug-Funktion aktuell abgeschaltet und kann ueber
`kEnableHeartbeatDebug` in der Firmware wieder aktiviert werden.

- schnelles Blinken: Reader-Fehler, aktuell kein Reader online
- langsames Blinken: Startwartephase vor der ersten PN5180-Initialisierung
- kurzer Puls etwa alle 2 Sekunden: Firmware laeuft, Reader online, kein Tag erkannt
- dauerhaft an: Tag aktuell erkannt

Im aktuellen Stand ist `ISO14443A` bereits der aktive Hauptpfad. Fuer weitere
Grenztests dienen deshalb vor allem `TYPEA_DIAG`, `TYPEA_TUNE` und
`TYPEA_SWEEP`.

## RP5 Client

Das integrierte Clientmodul fuer `abr` bleibt dasselbe wie beim PN532-Gateway:

- [abr/hardware/pico_gateway_client.py](../../abr/hardware/pico_gateway_client.py)

Terminal-Wrapper im Projekt:

- [hardware/pn5180_gateway_client.py](../../hardware/pn5180_gateway_client.py)

Kompatibilitaets-Wrapper an der Unterprojekt-Stelle:

- [rp5/pico_gateway_client.py](../../hardware/pn5180_gateway/rp5/pico_gateway_client.py)

Beispiele:

```bash
python3 hardware/pn5180_gateway_client.py
python3 hardware/pn5180_gateway_client.py STATUS 1
python3 hardware/pn5180_gateway_client.py STATUS_START
python3 hardware/pn5180_gateway_client.py STATUS_FETCH
python3 hardware/pn5180_gateway_client.py TYPEA_DIAG
python3 hardware/pn5180_gateway_client.py PING
python3 hardware/pn5180_gateway_client.py REINIT 1
python3 hardware/pn5180_gateway_client.py --timeout 90 TYPEA_SWEEP 1 20
```

Abweichendes UART-Geraet oder Timeout:

```bash
python3 hardware/pn5180_gateway_client.py --device /dev/ttyAMA0 --timeout 10 STATUS
```

## Aktueller Testablauf

Empfohlene Kurzsequenz auf dem Pi:

```bash
python3 hardware/pn5180_gateway_client.py --timeout 10 STATUS
python3 hardware/pn5180_gateway_client.py STATUS_START
python3 hardware/pn5180_gateway_client.py STATUS_FETCH
python3 hardware/pn5180_gateway_client.py --timeout 10 TYPEA_DIAG
```

Asynchroner Pfad fuer ein Hauptprogramm:

```bash
python3 hardware/pn5180_gateway_client.py STATUS_START
# hier kann das Hauptprogramm andere Arbeit erledigen
python3 hardware/pn5180_gateway_client.py STATUS_FETCH
```

Fuer `RXWAIT`-Vergleiche:

```bash
python3 hardware/pn5180_gateway_client.py --timeout 90 TYPEA_SWEEP 1 20
```

Wichtig:

- bei `TYPEA_SWEEP` erst dann den naechsten Befehl senden, wenn wirklich
  `END` erschienen ist
- sonst liest der naechste Clientaufruf leicht Restzeilen eines noch laufenden
  Sweeps ein
- der bisher beste feste `RXWAIT`-Standardwert ist `0x00000878`

## RP5 Test

UART auf dem Raspberry Pi 5 z. B. mit `115200 8N1` konfigurieren:

```bash
stty -F /dev/ttyAMA0 115200 raw -echo
```

Status anfordern:

```bash
printf 'STATUS\n' > /dev/ttyAMA0
timeout 1 cat /dev/ttyAMA0
```

Diagnose anfordern:

```bash
printf 'TYPEA_DIAG\n' > /dev/ttyAMA0
timeout 10 cat /dev/ttyAMA0
```

Clientskript verwenden:

```bash
cd /pfad/zu/abr
python3 hardware/pn5180_gateway_client.py PING
python3 hardware/pn5180_gateway_client.py STATUS
python3 hardware/pn5180_gateway_client.py TYPEA_DIAG
```

## Projektinhalt

- [src/pico_gateway.cpp](../../hardware/pn5180_gateway/src/pico_gateway.cpp): Gateway-Firmware
- [platformio.ini](../../hardware/pn5180_gateway/platformio.ini): Build-Konfiguration
- [lib/PN5180_Library_Minimal](../../hardware/pn5180_gateway/lib/PN5180_Library_Minimal/src/PN5180.h): lokaler PN5180-Minimalteil

## Lokale PN5180 Bibliothek

Das Unterprojekt fuehrt die benoetigte Teilmenge der `PN5180-Library` lokal mit:

- [lib/PN5180_Library_Minimal/src/PN5180.h](../../hardware/pn5180_gateway/lib/PN5180_Library_Minimal/src/PN5180.h)
- [lib/PN5180_Library_Minimal/src/PN5180.cpp](../../hardware/pn5180_gateway/lib/PN5180_Library_Minimal/src/PN5180.cpp)
- [lib/PN5180_Library_Minimal/src/PN5180ISO14443.h](../../hardware/pn5180_gateway/lib/PN5180_Library_Minimal/src/PN5180ISO14443.h)
- [lib/PN5180_Library_Minimal/src/PN5180ISO14443.cpp](../../hardware/pn5180_gateway/lib/PN5180_Library_Minimal/src/PN5180ISO14443.cpp)
- [lib/PN5180_Library_Minimal/src/PN5180ISO15693.h](../../hardware/pn5180_gateway/lib/PN5180_Library_Minimal/src/PN5180ISO15693.h)
- [lib/PN5180_Library_Minimal/src/PN5180ISO15693.cpp](../../hardware/pn5180_gateway/lib/PN5180_Library_Minimal/src/PN5180ISO15693.cpp)

Grund fuer die lokale Mitfuehrung:

- reproduzierbarer Build ohne Registry-Zwang
- dieselbe Repo-Strategie wie beim `pn532_gateway`
- nur die fuer das Gateway benoetigte Arduino-Teilmenge liegt im Projekt

## AGC-Ausgabe pro Leseversuch

Bei STATUS-Probes und beim Polling erscheint auf USB-Serial eine `Messung`-Zeile
auch dann, wenn kein Tag gelesen wurde. Protokoll, REQA/WUPA-Runde bzw. Inventory
und `sample_ms` (Millisekunden seit Pico-Start) ordnen den Wert dem Versuch zu.
Die UART-Antwortstruktur bleibt unveraendert.

- `AGC_SAMPLE=last_rx_end`: RF_STATUS wurde nach Erkennen des letzten RX-Endes
  gelesen, vor FIFO-Verarbeitung, Idle-Aufraeumen, RF-off und Reset. Bei Type A
  ist dies normalerweise das letzte SAK; bei einem spaeteren Fehler kann es die
  letzte erfolgreich abgeschlossene Empfangsphase derselben Runde sein.
- `AGC_SAMPLE=timeout`: Registeraufnahme am Ende des erfolglosen Empfangswartens
  (bei ISO15693 auch nach der initialen Wartezeit ohne SOF).
- `AGC=-`: kein gueltiger Registerwert. Ein alter Wert wird nicht ersatzweise
  ausgegeben. `AGC_SAMPLE=unavailable` bezeichnet einen fehlenden Snapshot.
- Die Snapshot-Werte werden nach RF-off nicht nochmals aus dem Chip gelesen.
  Die Meldung `Tag entfernt` enthaelt keine irrefuehrenden alten Messwerte mehr.

AGC ist der 10-Bit-Regelwert aus RF_STATUS, keine kalibrierte Tag-Signalstaerke.
Dies sind **Host-Snapshots**, keine Hardware-Latches des Wertes waehrend eines
Telegramms. SPI-Zugriffe und das IRQ-Polling verursachen Verzoegerung (Type A
1-ms-Pollpausen; ISO15693 bisherige 10-ms-Warteintervalle). Der PN5180 kann AGC
inzwischen aktualisieren. Die Ausgabe garantiert die Zuordnung zur aktuellen
Runde und die Aufnahme vor dem Aufraeumen, nicht einen konstanten AGC-Wert
waehrend der gesamten Tag-Antwort. Die AGC-Regelung wird nicht eingefroren und
EEPROM-/RF-Konfigurationen werden nicht veraendert.

Referenz: NXP PN5180 Datenblatt, RF_STATUS/AGC_CONFIG und DPC Config:
https://www.nxp.com/docs/en/data-sheet/PN5180A0XX_C3_C4.pdf

Host-Regressionstest (Snapshot bei RX, Timeout und fehlgeschlagenem Registerlesen):

```sh
python3 tests/test_agc_snapshot.py
```

Hardware-Abnahme nach dem Flashen: STATUS ohne Tag, mit ISO14443A-Tag, mit
ISO15693-Tag und nach Entfernen des Tags ausfuehren; auf Protokoll, Zeitstempel,
Timeout-Markierung und fehlende Altwerte achten. Ein Host-Test ersetzt keine
Messung der tatsaechlichen AGC-Dynamik am Reader.

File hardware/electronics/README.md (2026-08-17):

# Electronics Uebersicht

Dieses Verzeichnis enthaelt die aktuellen KiCad-Hardwareprojekte des ABR-Aufbaus.

## Aktive Teilprojekte

- [abr_pi5_header](../../hardware/electronics/abr_pi5_header/abr_pi5_header.kicad_sch)
  - Hauptverdrahtung rund um den `Raspberry Pi 5`
  - Audio (`MAX98357A`), NFC-Anbindung, Bedien- und Lichtsignale

- [control_panel](../../hardware/electronics/control_panel/control_panel.kicad_sch)
  - separates Bedienpanel
  - `EC11` Drehencoder sowie Haupttaster wie `Button_Start`
  - eigene Produktionsdaten unter
    [production](../../hardware/electronics/control_panel/production)

- [LED_bar_long](../../hardware/electronics/LED_bar_long/LED_bar_long.kicad_sch)
  - aktuell gepflegte LED-Leiste fuer die Beleuchtung
  - Fertigungsdaten unter
    [production](../../hardware/electronics/LED_bar_long/production)

Aktueller Verdrahtungshinweis fuer den realen Scanneraufbau:

- die Beleuchtung wird jetzt getrennt links/rechts geschaltet
- `LED-left` haengt an einer MOSFET-Stufe auf `BCM12`
- `LED-right` haengt an einer MOSFET-Stufe auf `BCM13`

## Historischer Hinweis

Das fruehere Projekt `LED_bar_short` ist nicht mehr der aktive Pfad. Die aktuellen Arbeitsstaende liegen bei `LED_bar_long`, `control_panel` und `abr_pi5_header`.

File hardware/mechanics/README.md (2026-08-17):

# Mechanics Uebersicht

Dieses Verzeichnis enthaelt die aktuellen mechanischen Dateien fuer den Scanner-Rohaufbau.

## Dateitypen

- `*.f3d` und `*.f3z`
  - Fusion-Quellmodelle
- `*.3mf`
  - Austausch- bzw. Druckvorbereitungsdateien
- `*.stl`
  - direkte Druck-/Mesh-Exporte

## Aktuelle Bauteilgruppen

Die vorhandenen Dateien decken bereits mehrere Bereiche des Aufbaus ab:

- Grundkoerper und Seiten:
  - `base_left`, `base_right`, `side_left`, `side_right`
- Front-/Rueckteile:
  - `front`, `front2`, `back`, `back2`, `lower_front2`, `upper_front2`
- Licht- und Strukturteile:
  - `LED_wedge_left`, `LED_wedge_right`, `bar`, `foot`
- Kameraaufnahme:
  - `camera_block_left`

Die Mechanikdateien sind aktuell als Arbeitsstand zu verstehen, nicht als formal eingefrorene Fertigungsfreigabe.

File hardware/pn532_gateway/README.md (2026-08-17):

# PN532 Pico Gateway

Dieses Unterprojekt enthaelt die aktuelle NFC-Hardwareanbindung fuer `abr`:

- ein Raspberry Pi Pico als Gateway
- zwei PN532-Module, jeweils an einem eigenen I2C-Bus des Pico
- ein Raspberry Pi 5, der den Pico per UART abfragt

Der aktuelle Firmware-Stand aktiviert standardmaessig nur `PN532 #1`. `PN532 #2`
ist vorbereitet, aber in der Firmware per `kEnableReader2 = false` abgeschaltet.

Auf dem derzeitigen Stand ist also:

- Reader `1` der aktive Referenzpfad
- Reader `2` elektrisch und softwareseitig vorbereitet
- die Freischaltung des zweiten Readers noch bewusst nicht Default

## Konzept

Die Architektur ist:

- `PN532 #1` an Pico-I2C-Bus auf `GP4/GP5`
- `PN532 #2` an Pico-I2C-Bus auf `GP6/GP7`
- UART zwischen Pico und RP5 ueber `GP0/GP1` bzw. `GPIO15/GPIO14`
- der Pico uebernimmt Initialisierung, Reconnect, Tag-Polling und Statushaltung
- der RP5 fragt den Pico nur noch per Textkommando ab

Beide PN532 duerfen dieselbe I2C-Adresse `0x24` haben, weil sie auf getrennten Bussen liegen.

## Firmware

- PlatformIO-Environment: `pico`
- Quelle: [src/pico_gateway.cpp](../../hardware/pn532_gateway/src/pico_gateway.cpp)

Build:

```bash
pio run -e pico
```

Die erzeugte UF2-Datei liegt danach unter:

```bash
.pio/build/pico/firmware.uf2
```

## Verdrahtung

### UART zum Raspberry Pi 5

Pico:

- `GP0` = TX zum RP5
- `GP1` = RX vom RP5
- `GND` gemeinsam

RP5:

- `GPIO15 / RXD` <- Pico `GP0 / TX`
- `GPIO14 / TXD` -> Pico `GP1 / RX`
- `GND` gemeinsam

Wichtig: nur 3,3-V-Pegel verwenden.

### PN532 #1

- `GP4` -> `SDA`
- `GP5` -> `SCL`
- `3V3` -> `VCC`
- `GND` -> `GND`

### PN532 #2

- `GP6` -> `SDA`
- `GP7` -> `SCL`
- `3V3` -> `VCC`
- `GND` -> `GND`

## UART Protokoll

Der Pico akzeptiert zeilenbasierte ASCII-Kommandos mit Newline.

Befehle:

- `PING`
- `STATUS`
- `STATUS 1`
- `STATUS 2`
- `REINIT`
- `REINIT 1`
- `REINIT 2`
- `DIAG`
- `HELP`

Beispielantwort auf `STATUS`:

```text
OK uptime_ms=12345
READER id=1 label=PN532-1 enabled=1 online=1 fw=0x32010607 tag=0 uid=- irq_mode=1 last_error=none
READER id=2 label=PN532-2 enabled=0 online=0 fw=0x00000000 tag=0 uid=- irq_mode=-1 last_error=boot
END
```

## Flashen

Die Datei `.pio/build/pico/firmware.uf2` auf den Pico im Bootloader-Modus kopieren.

Serieller Monitor waehrend der Entwicklung:

```bash
pio device monitor -b 115200
```

## RP5 Client

Das integrierte Clientmodul fuer `abr` liegt unter:

- [abr/hardware/pico_gateway_client.py](../../abr/hardware/pico_gateway_client.py)

Terminal-Wrapper im Projekt:

- [hardware/pn532_gateway_client.py](../../hardware/pn532_gateway_client.py)

Kompatibilitaets-Wrapper an der urspruenglichen Unterprojekt-Stelle:

- [rp5/pico_gateway_client.py](../../hardware/pn532_gateway/rp5/pico_gateway_client.py)

Beispiele:

```bash
python3 hardware/pn532_gateway_client.py
python3 hardware/pn532_gateway_client.py STATUS 1
python3 hardware/pn532_gateway_client.py DIAG
python3 hardware/pn532_gateway_client.py PING
python3 hardware/pn532_gateway_client.py REINIT 2
```

Abweichendes UART-Geraet oder Timeout:

```bash
python3 hardware/pn532_gateway_client.py --device /dev/ttyAMA0 --timeout 2.0 STATUS
```

Auf dem aktuell eingerichteten Pi ist `ttyAMA0` der relevante Header-UART. `serial0` kann auf anderen Pi-Setups abweichend gemappt sein.

## RP5 Test

UART auf dem Raspberry Pi 5 z. B. mit `115200 8N1` konfigurieren:

```bash
stty -F /dev/ttyAMA0 115200 raw -echo
```

Status anfordern:

```bash
printf 'STATUS\n' > /dev/ttyAMA0
timeout 1 cat /dev/ttyAMA0
```

Diagnose anfordern:

```bash
printf 'DIAG\n' > /dev/ttyAMA0
timeout 1 cat /dev/ttyAMA0
```

Clientskript verwenden:

```bash
cd /pfad/zu/abr
python3 hardware/pn532_gateway_client.py PING
python3 hardware/pn532_gateway_client.py STATUS
```

## Projektinhalt

- [src/pico_gateway.cpp](../../hardware/pn532_gateway/src/pico_gateway.cpp): Gateway-Firmware
- [lib/Seeed_Arduino_NFC_Minimal](../../hardware/pn532_gateway/lib/Seeed_Arduino_NFC_Minimal/src/PN532/PN532/PN532.h): lokaler PN532-I2C-Minimalteil
- [platformio.ini](../../hardware/pn532_gateway/platformio.ini): Build-Konfiguration

## Lokale PN532 Bibliothek

Die fuer dieses Projekt benoetigte PN532-I2C-Teilmenge liegt lokal unter:

- [lib/Seeed_Arduino_NFC_Minimal/src/PN532/PN532/PN532.h](../../hardware/pn532_gateway/lib/Seeed_Arduino_NFC_Minimal/src/PN532/PN532/PN532.h)
- [lib/Seeed_Arduino_NFC_Minimal/src/PN532/PN532/PN532.cpp](../../hardware/pn532_gateway/lib/Seeed_Arduino_NFC_Minimal/src/PN532/PN532/PN532.cpp)
- [lib/Seeed_Arduino_NFC_Minimal/src/PN532/PN532_I2C/PN532_I2C.cpp](../../hardware/pn532_gateway/lib/Seeed_Arduino_NFC_Minimal/src/PN532/PN532_I2C/PN532_I2C.cpp)

Der Grund ist pragmatisch: fuer den Pico wird nur der I2C-Pfad benoetigt, waehrend die komplette Seeed-Library auf dem verwendeten RP2040-Mbed-Core an unbenutzten SPI- und SoftwareSerial-Backends scheitert.

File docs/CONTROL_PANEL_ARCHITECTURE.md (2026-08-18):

# Control Panel Architecture

Last reviewed: `2026-08-01`

Deutsche Fassung: [Bedienpanel-Architektur](../docs_DE/CONTROL_PANEL_ARCHITECTURE.md)

## Goal

The ABR device's control logic is designed to run continuously on the
`Raspberry Pi 5` while:

- monitoring the buttons and `EC11` at all times
- separating hardware events from application logic
- remaining responsive during capture, OCR, TTS, and NFC operations

## Implemented Structure

The current Raspberry Pi path consists of four clearly separated layers:

1. `GPIO backend`
   - direct GPIO access through `RPi.GPIO`, based on `rpi-lgpio`
   - test fallback: `pinctrl`
2. `FrontPanelMonitor`
   - button polling in a long-lived thread
   - GPIO edge interrupts for both EC11 channels with `rpi-gpio`
   - button debouncing
   - `EC11` decoding
   - hardware-event generation only
3. `Action Router`
   - translates hardware events into application actions
   - also detects the three-button combination that opens the book deletion
     dialog
4. `Runtime Controller`
   - processes actions
   - controls jobs, audio, book context, and error paths

## EC11 Interrupts and Button Polling

With the production `rpi-gpio` backend, the EC11 uses edge interrupts on
channels A and B. The callback reads both signal levels as one snapshot and
performs only time-critical, non-blocking work:

- update the quadrature decoder
- change the thread-safe target volume held in memory
- enqueue a regular encoder event for logging and mixer synchronization

The interrupt does not start `amixer`, audio, or any other subprocesses. This
prevents long callback execution times. Mechanical buttons continue to use
the proven polling and debounce mechanism. If only `pinctrl` is available,
the encoder also continues to work through polling; the monitor thread then
updates the target-volume variable directly.

- buttons: polling with debounce
- encoder: edge interrupts with quadrature decoding and a polling fallback
- application logic: still runs after event translation; only the atomic
  target value is changed inside the callback

## Polling Fallback

The monitor uses two timing ranges:

- idle: `2.0 ms`
- during encoder activity: `0.5 ms`
- `encoder_active_hold_ms`: `25 ms`
- button debounce: `25 ms`

These short intervals apply to button snapshots and the encoder fallback.
When GPIO interrupts are active, encoder levels are not decoded again through
the polling path.

## Current Control Assignments

### `Start / Stop / NFC`

- starts the real `capture -> image preparation -> OCR -> page ingest` run
- stops an active foreground job
- stops active page playback
- also stops a heartbeat-only waiting state

### `EC11`

- changes the volume directly
- remains operational during page and system-audio playback, including
  `bing.wav`
- the interrupt updates only the target value; mixer access, logging, and
  other subprocesses continue to run outside the callback
- WAV playback itself checks the target value block by block; buffering and
  underrun protection are described in
  [CONTROL_RUNTIME_ARCHITECTURE.md](CONTROL_RUNTIME_ARCHITECTURE.md)

### `EC11 button`

- currently used in production only by the book deletion dialog

### Three-button combination

Simultaneously pressing:

- `Start / Stop / NFC`
- `Book summary`
- `Chapter/latest-pages summary`

opens the book deletion dialog.

## Production Summary Buttons

### `Chapter/latest-pages summary`

- first plays `kapitel_zusammenfassen`
- then starts a `bing` heartbeat until audio playback begins
- first assembles any sections that can now be completed, then examines the
  text from the persistent open-section boundary
- combines open text with the most recent available section summary to create
  a temporary recap
- before the first completed section, summarizes the open text by itself
- does not persist this temporary recap
- when there is no open text, continues to retrieve the latest available
  section summary and can generate or refresh it through Gemini as needed

### `Book summary`

- first plays `buch_zusammenfassen`
- then starts a `bing` heartbeat until audio playback begins
- creates an up-to-date “story so far” recap from all available section
  summaries

### Missing Summary Content

- the runtime plays `keine_zusammenfassung` only when neither a completed
  section nor open text is available

## Relevant Files

- [abr/hardware/control_panel.py](../abr/hardware/control_panel.py)
- [abr/control/frontpanel.py](../abr/control/frontpanel.py)
- [abr/control/runtime.py](../abr/control/runtime.py)
- [hardware/control_panel_service.py](../hardware/control_panel_service.py)

## Next Practical Improvements

At the control-panel level, the next useful work is no longer basic wiring but
refinement and operational readiness:

1. Continue testing the summary heartbeat and error messages on the actual Pi.
2. Add status or telemetry events for section and summary processing.
3. Add `systemd` startup for the runtime service at a later stage.

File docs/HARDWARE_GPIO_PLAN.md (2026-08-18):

# Hardware and GPIO Plan

Last reviewed: `2026-08-18`

Deutsche Fassung: [Hardware- und GPIO-Plan](../docs_DE/HARDWARE_GPIO_PLAN.md)

## Purpose

This document describes the current ABR target hardware and the GPIO
assignment on the `Raspberry Pi 5`.

The controls use a small number of tactile, clearly distinguishable elements:

- `1 x EC11` rotary encoder for volume
- `1 x` push button integrated into the encoder
- `3 x` separate main buttons

## Control Concept

1. `Volume`
   - turn left or right to decrease or increase volume
   - press the encoder for an additional button function
2. `Start / Stop / NFC`
   - starts the NFC query, scan, and audio playback
   - stops an active job or audio playback
3. `Book summary`
   - generates and reads the current book summary
4. `Chapter/latest-pages summary`
   - summarizes the latest relevant section, including open pages

All buttons are wired `active-low` to `GND` and use the Pi's internal pull-ups.
The Start button should be the largest and easiest to locate. The two summary
buttons should be distinguishable by touch.

## Current Hardware

- main computer: `Raspberry Pi 5`
- NFC gateway: `Raspberry Pi Pico`/`RP2040`, connected to the Pi through UART
- NFC readers: `PN5180` or `PN532`, connected exclusively to the Pico
- audio: `MAX98357A` through `I2S`
- controls: `EC11` with push button and three function buttons
- cameras: `2 x Arducam IMX519 16 MP` with 140-degree M12 wide-angle lenses
- camera connection: the two CSI ports on the Pi 5
- lighting: two separately switched LED channels, each driven through a MOSFET

Current hardware sources in the repository:

- Pi main wiring: [hardware/electronics/abr_pi5_header](../hardware/electronics/abr_pi5_header)
- control panel: [hardware/electronics/control_panel](../hardware/electronics/control_panel)
- LED bar: [hardware/electronics/LED_bar_long](../hardware/electronics/LED_bar_long)
- mechanics: [hardware/mechanics](../hardware/mechanics)

`LED_bar_short` is historical and is no longer the active electronics path.

Logical camera assignment:

- left camera on `CAM0`
- right camera on `CAM1`

The cameras use the CSI ports and occupy no GPIOs. The current remaps are
stored at `calibration/out/cam0_planar.npz` and
`calibration/out/cam1_planar.npz`.

## NFC Architecture

There is **no direct communication** between the Raspberry Pi 5 and a
`PN5180` or `PN532` reader. The Pi communicates exclusively with the
Raspberry Pi Pico. The Pico handles reader initialization, protocol access,
tag detection, and status tracking.

The Pi-to-Pico connection is a `115200 8N1` UART using 3.3 V logic levels:

| Raspberry Pi 5 | Physical | Direction | Raspberry Pi Pico | Function |
| --- | --- | --- | --- | --- |
| `BCM14 / TXD` | `8` | Pi → Pico | `GP1 / RX` | commands to the gateway |
| `BCM15 / RXD` | `10` | Pico → Pi | `GP0 / TX` | gateway responses |
| `GND` | any GND pin | shared | `GND` | common reference |

The Pi software uses `/dev/ttyAMA0` by default. The gateway provides a
line-oriented ASCII protocol; the shared client is implemented in
[abr/hardware/pico_gateway_client.py](../abr/hardware/pico_gateway_client.py).

### Current PN5180 Gateway Path

The current preferred path uses up to two PN5180 readers on the Pico's shared
`SPI0` bus. Both readers are active in the current dual-reader firmware, but
are enabled strictly one at a time. They remain in reset while idle.

Pico assignment:

- UART to the Pi: `GP0` = TX, `GP1` = RX
- shared SPI0 bus:
  - `GP16` = MISO
  - `GP18` = SCK
  - `GP19` = MOSI
- PN5180 #1:
  - `GP2` = NSS
  - `GP3` = BUSY
  - `GP4` = RESET
  - `GP5` = IRQ
- PN5180 #2:
  - `GP6` = NSS
  - `GP7` = BUSY
  - `GP8` = RESET
  - `GP9` = IRQ

Firmware and complete wiring details:
[hardware/pn5180_gateway/README.md](../hardware/pn5180_gateway/README.md).

### Alternative PN532 Gateway Path

The alternative Pico path uses two separate I²C buses, allowing both PN532
readers to use the same `0x24` address:

- PN532 #1: `GP4` = SDA, `GP5` = SCL
- PN532 #2: `GP6` = SDA, `GP7` = SCL
- UART to the Pi remains on `GP0/GP1`

In the current default PN532 firmware, reader 1 is active and reader 2 is
prepared but disabled. Details are provided in
[hardware/pn532_gateway/README.md](../hardware/pn532_gateway/README.md).

## Final Raspberry Pi 5 GPIO Assignment

| BCM | Physical | Direction/bus | Function | Notes |
| --- | --- | --- | --- | --- |
| `BCM4` | `7` | Out | `MAX98357A SD_MODE` | optional, planned for the target device |
| `BCM5` | `29` | In | `EC11 A` | encoder channel A |
| `BCM6` | `31` | In | `EC11 B` | encoder channel B |
| `BCM12` | `32` | Out | `LED-left` | MOSFET logic signal, PWM-capable |
| `BCM13` | `33` | Out | `LED-right` | MOSFET logic signal, PWM-capable |
| `BCM14 / TXD` | `8` | UART Out | Pico `GP1 / RX` | Pi sends gateway commands |
| `BCM15 / RXD` | `10` | UART In | Pico `GP0 / TX` | Pi receives gateway responses |
| `BCM16` | `36` | In | `EC11 button` | volume-knob push function |
| `BCM17` | `11` | In | `Start / Stop / NFC` | main button |
| `BCM18` | `12` | I2S BCLK | `MAX98357A BCLK` | dedicated |
| `BCM19` | `35` | I2S LRCLK | `MAX98357A LRC / WS` | dedicated |
| `BCM21` | `40` | I2S DIN | `MAX98357A DIN` | dedicated |
| `BCM22` | `15` | In | `Book summary` | separate button |
| `BCM24` | `18` | In | `Chapter/latest-pages summary` | separate button |

The Pi has no NFC-specific SPI, I²C, `NSS`, `BUSY`, `IRQ`, or `RESET` lines.
In particular, the pins formerly listed for a direct PN5180 path—`BCM7`,
`BCM8`, `BCM9`, `BCM10`, `BCM11`, `BCM23`, and `BCM25`—are no longer reserved
for NFC.

## Reserved and Free Pins

| BCM | Physical | Status | Reason |
| --- | --- | --- | --- |
| `BCM0` | `27` | reserved | EEPROM/HAT special use |
| `BCM1` | `28` | reserved | EEPROM/HAT special use |
| `BCM2` | `3` | keep free | I²C reserve for future Pi extensions |
| `BCM3` | `5` | keep free | I²C reserve for future Pi extensions |
| `BCM7`–`BCM11` | `26, 24, 21, 19, 23` | free | no direct NFC SPI path |
| `BCM14` | `8` | used | UART TXD to the Pico |
| `BCM15` | `10` | used | UART RXD from the Pico |
| `BCM20` | `38` | free | future extension |
| `BCM23` | `16` | free | no direct NFC IRQ |
| `BCM25` | `22` | free | no direct NFC BUSY |
| `BCM26` | `37` | free | future extension |
| `BCM27` | `13` | free | future extension |

## Electrical and Operational Notes

### Pico and NFC

- Pi and Pico require a common ground.
- UART uses 3.3 V logic; do not connect 5 V UART signals.
- `TXD` and `RXD` are crossed: Pi TX to Pico RX, Pico TX to Pi RX.
- Connect PN5180 or PN532 readers only to the Pico as described in the
  corresponding gateway README.
- Switching between the PN5180 and PN532 gateways does not alter Pi wiring.

### Audio and Lighting

- `BCM18`, `BCM19`, and `BCM21` are dedicated to I²S.
- `BCM12` and `BCM13` provide logic signals to the MOSFET drivers only.
- LED loads must not be powered directly from a GPIO.
- [hardware/led_light_test.py](../hardware/led_light_test.py) is available for
  hardware tests.

### Buttons and Encoder

- All four button inputs can be operated `active-low` with internal pull-ups.
- Buttons are debounced in software.
- The production GPIO backend decodes the EC11 using edge interrupts, with a
  polling fallback available.

## Software Implications

The hardware split is represented by the following software components:

- GPIO abstraction for buttons, encoder, and lighting
- one shared UART gateway client for the Pico
- gateway firmware for either PN5180 or PN532
- capture orchestration for NFC query, lighting, cameras, OCR, and TTS
- state logic for start, stop, playback, and summaries

The Raspberry Pi contains no PN5180 or PN532 driver path. Changes to reader
communication belong in the corresponding Pico firmware; the Pi application
remains limited to the UART protocol.

## Summary

The Raspberry Pi 5 directly controls the front panel, lighting, cameras, and
audio. All NFC hardware is encapsulated behind the Raspberry Pi Pico. Apart
from a shared ground, the only connections between Pi and Pico are the UART
lines `BCM14/TXD` and `BCM15/RXD`.

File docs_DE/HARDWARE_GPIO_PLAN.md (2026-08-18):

# Hardware- und GPIO-Plan

Stand: `2026-08-18`

English version: [Hardware and GPIO Plan](../docs/HARDWARE_GPIO_PLAN.md)

## Ziel

Dieses Dokument beschreibt den aktuellen Hardwareaufbau des ABR-Zielgeräts
und die GPIO-Belegung am `Raspberry Pi 5`.

Der Bedienpfad verwendet wenige, taktil klar unterscheidbare Elemente:

- `1 x EC11`-Drehencoder für die Lautstärke
- `1 x` Drucktaster im Encoder
- `3 x` separate Haupttaster

## Bedienkonzept

1. `Lautstärke`
   - Encoder links/rechts für leiser/lauter
   - Encoder-Drucktaster als zusätzliche Taste
2. `Start / Stop / NFC`
   - startet NFC-Abfrage, Scan und Audioausgabe
   - stoppt einen laufenden Job oder die Audioausgabe
3. `Buch-Zusammenfassung`
   - erzeugt und liest die bisherige Buchzusammenfassung
4. `Kapitel-/Letzte-Seiten-Zusammenfassung`
   - fasst den letzten relevanten Abschnitt einschließlich offener Seiten
     zusammen

Alle Taster werden `active-low` gegen `GND` betrieben und verwenden interne
Pull-ups des Pi. Der Starttaster soll mechanisch am größten und leicht
auffindbar sein; die beiden Zusammenfassungstaster sollen sich taktil
unterscheiden.

## Aktuelle Hardware

- Hauptrechner: `Raspberry Pi 5`
- NFC-Gateway: `Raspberry Pi Pico`/`RP2040`, per UART mit dem Pi verbunden
- NFC-Reader: `PN5180` oder `PN532`, ausschließlich am Pico angeschlossen
- Audio: `MAX98357A` über `I2S`
- Bedienung: `EC11` mit Drucktaster und drei Funktionstaster
- Kameras: `2 x Arducam IMX519 16 MP` mit 140-Grad-M12-Weitwinkelobjektiv
- Kameraanschluss: die beiden CSI-Ports des Pi 5
- Licht: zwei getrennte LED-Kanäle, jeweils über einen MOSFET geschaltet

Aktuelle Hardware-Arbeitsstände im Repository:

- Pi-Hauptverdrahtung: [hardware/electronics/abr_pi5_header](../hardware/electronics/abr_pi5_header)
- Bedienpanel: [hardware/electronics/control_panel](../hardware/electronics/control_panel)
- LED-Leiste: [hardware/electronics/LED_bar_long](../hardware/electronics/LED_bar_long)
- Mechanik: [hardware/mechanics](../hardware/mechanics)

`LED_bar_short` ist nur noch historisch und nicht der aktive Elektronikpfad.

Logische Kamerazuordnung:

- linke Kamera an `CAM0`
- rechte Kamera an `CAM1`

Die Kameras verwenden die CSI-Ports und belegen keine GPIOs. Die aktuellen
Remaps liegen unter `calibration/out/cam0_planar.npz` und
`calibration/out/cam1_planar.npz`.

## NFC-Architektur

Es gibt **keine direkte Kommunikation** zwischen dem Raspberry Pi 5 und einem
`PN5180`- oder `PN532`-Reader. Der Pi kommuniziert ausschließlich mit dem
Raspberry Pi Pico. Der Pico übernimmt Reader-Initialisierung,
Protokollzugriff, Tag-Erkennung und Statushaltung.

Die Verbindung zwischen Pi und Pico ist ein UART mit `115200 8N1` und
3,3-V-Logikpegeln:

| Raspberry Pi 5 | Physisch | Richtung | Raspberry Pi Pico | Funktion |
| --- | --- | --- | --- | --- |
| `BCM14 / TXD` | `8` | Pi → Pico | `GP1 / RX` | Kommandos an das Gateway |
| `BCM15 / RXD` | `10` | Pico → Pi | `GP0 / TX` | Antworten des Gateways |
| `GND` | beliebiger GND-Pin | gemeinsam | `GND` | gemeinsames Bezugspotential |

Auf dem Pi verwendet die Software standardmäßig `/dev/ttyAMA0`. Das Gateway
spricht ein zeilenbasiertes ASCII-Protokoll; der gemeinsame Client liegt in
[abr/hardware/pico_gateway_client.py](../abr/hardware/pico_gateway_client.py).

### Aktueller PN5180-Gateway-Pfad

Der bevorzugte aktuelle Pfad verwendet bis zu zwei PN5180 am gemeinsamen
`SPI0`-Bus des Pico. Beide Reader sind im aktuellen Zwei-Reader-Firmwarepfad
aktiv, werden jedoch strikt nacheinander freigegeben. Im Leerlauf bleiben sie
im Reset.

Pico-Belegung:

- UART zum Pi: `GP0` = TX, `GP1` = RX
- gemeinsamer SPI0-Bus:
  - `GP16` = MISO
  - `GP18` = SCK
  - `GP19` = MOSI
- PN5180 #1:
  - `GP2` = NSS
  - `GP3` = BUSY
  - `GP4` = RESET
  - `GP5` = IRQ
- PN5180 #2:
  - `GP6` = NSS
  - `GP7` = BUSY
  - `GP8` = RESET
  - `GP9` = IRQ

Firmware und vollständige Verdrahtung:
[hardware/pn5180_gateway/README.md](../hardware/pn5180_gateway/README.md).

### Alternativer PN532-Gateway-Pfad

Der alternative Pico-Pfad verwendet zwei getrennte I²C-Busse. Dadurch dürfen
beide PN532 dieselbe Adresse `0x24` verwenden:

- PN532 #1: `GP4` = SDA, `GP5` = SCL
- PN532 #2: `GP6` = SDA, `GP7` = SCL
- UART zum Pi unverändert über `GP0/GP1`

Im aktuellen PN532-Firmwarestandard ist Reader 1 aktiv und Reader 2
vorbereitet, aber deaktiviert. Details stehen in
[hardware/pn532_gateway/README.md](../hardware/pn532_gateway/README.md).

## Finale GPIO-Belegung am Raspberry Pi 5

| BCM | Physisch | Richtung/Bus | Funktion | Bemerkung |
| --- | --- | --- | --- | --- |
| `BCM4` | `7` | Out | `MAX98357A SD_MODE` | optional, für das Zielgerät vorgesehen |
| `BCM5` | `29` | In | `EC11 A` | Encoderkanal A |
| `BCM6` | `31` | In | `EC11 B` | Encoderkanal B |
| `BCM12` | `32` | Out | `LED-left` | Logiksignal zum MOSFET, PWM-tauglich |
| `BCM13` | `33` | Out | `LED-right` | Logiksignal zum MOSFET, PWM-tauglich |
| `BCM14 / TXD` | `8` | UART Out | Pico `GP1 / RX` | Pi sendet Gateway-Kommandos |
| `BCM15 / RXD` | `10` | UART In | Pico `GP0 / TX` | Pi empfängt Gateway-Antworten |
| `BCM16` | `36` | In | `EC11-Taster` | Druckfunktion des Lautstärkeknopfs |
| `BCM17` | `11` | In | `Start / Stop / NFC` | Haupttaster |
| `BCM18` | `12` | I2S BCLK | `MAX98357A BCLK` | fest belegt |
| `BCM19` | `35` | I2S LRCLK | `MAX98357A LRC / WS` | fest belegt |
| `BCM21` | `40` | I2S DIN | `MAX98357A DIN` | fest belegt |
| `BCM22` | `15` | In | `Buch-Zusammenfassung` | separater Taster |
| `BCM24` | `18` | In | `Kapitel-/Letzte-Seiten-Zusammenfassung` | separater Taster |

Am Pi gibt es keine NFC-spezifischen SPI-, I²C-, `NSS`-, `BUSY`-, `IRQ`- oder
`RESET`-Leitungen. Insbesondere sind die früher für einen direkten PN5180-Pfad
genannten Pins `BCM7`, `BCM8`, `BCM9`, `BCM10`, `BCM11`, `BCM23` und `BCM25`
nicht mehr für NFC reserviert.

## Reservierte und freie Pins

| BCM | Physisch | Status | Grund |
| --- | --- | --- | --- |
| `BCM0` | `27` | reserviert | EEPROM-/HAT-Sonderfall |
| `BCM1` | `28` | reserviert | EEPROM-/HAT-Sonderfall |
| `BCM2` | `3` | frei halten | I²C-Reserve für spätere Pi-Erweiterungen |
| `BCM3` | `5` | frei halten | I²C-Reserve für spätere Pi-Erweiterungen |
| `BCM7`–`BCM11` | `26, 24, 21, 19, 23` | frei | kein direkter NFC-SPI-Pfad mehr |
| `BCM14` | `8` | belegt | UART TXD zum Pico |
| `BCM15` | `10` | belegt | UART RXD vom Pico |
| `BCM20` | `38` | frei | spätere Erweiterung |
| `BCM23` | `16` | frei | kein direkter NFC-IRQ mehr |
| `BCM25` | `22` | frei | kein direkter NFC-BUSY mehr |
| `BCM26` | `37` | frei | spätere Erweiterung |
| `BCM27` | `13` | frei | spätere Erweiterung |

## Elektrische und betriebliche Hinweise

### Pico und NFC

- Pi und Pico benötigen eine gemeinsame Masse.
- Die UART-Leitungen arbeiten mit 3,3-V-Pegeln; keine 5-V-UART-Signale
  anschließen.
- `TXD` und `RXD` werden gekreuzt: Pi-TX an Pico-RX, Pico-TX an Pi-RX.
- PN5180 und PN532 werden ausschließlich nach der jeweiligen Gateway-README
  am Pico verdrahtet.
- Ein Wechsel zwischen PN5180- und PN532-Gateway ändert die Pi-Verdrahtung
  nicht.

### Audio und Licht

- `BCM18`, `BCM19` und `BCM21` sind durch I²S belegt.
- `BCM12` und `BCM13` liefern nur Logiksignale für die MOSFET-Treiber.
- LED-Lasten dürfen nicht direkt aus einem GPIO versorgt werden.
- Für Hardwaretests steht
  [hardware/led_light_test.py](../hardware/led_light_test.py) bereit.

### Taster und Encoder

- Alle vier Tastereingänge können `active-low` mit internen Pull-ups betrieben
  werden.
- Taster werden softwareseitig entprellt.
- Der EC11 wird im produktiven GPIO-Backend über Flankeninterrupts dekodiert;
  ein Polling-Fallback bleibt vorhanden.

## Softwarefolgen

Die Hardwareaufteilung wird in der Software durch folgende Bausteine
abgebildet:

- GPIO-Abstraktion für Taster, Encoder und Licht
- ein gemeinsamer UART-Gateway-Client für den Pico
- Gateway-Firmware für PN5180 beziehungsweise PN532
- Capture-Orchestrierung für NFC-Abfrage, Licht, Kameras, OCR und TTS
- Zustandslogik für Start, Stop, Wiedergabe und Zusammenfassungen

Der Raspberry Pi enthält keinen PN5180- oder PN532-Treiberpfad. Änderungen an
der Reader-Kommunikation gehören in die jeweilige Pico-Firmware; die
Pi-Anwendung bleibt auf das UART-Protokoll beschränkt.

## Kurzfazit

Der Raspberry Pi 5 steuert Bedienpanel, Licht, Kameras und Audio direkt. Die
gesamte NFC-Hardware ist hinter dem Raspberry Pi Pico gekapselt. Zwischen Pi
und Pico existieren neben gemeinsamer Masse nur die UART-Leitungen
`BCM14/TXD` und `BCM15/RXD`.

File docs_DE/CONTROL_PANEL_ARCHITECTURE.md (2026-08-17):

# Control Panel Architecture

Stand: `2026-08-01`

## Ziel

Die Bedienlogik des ABR-Geraets soll dauerhaft auf dem `Raspberry Pi 5` laufen
und dabei:

- Taster und `EC11` permanent ueberwachen
- Hardwareereignisse von der fachlichen Logik trennen
- auch waehrend Capture, OCR, TTS und NFC reaktionsfaehig bleiben

## Tatsachlich implementierte Struktur

Der aktuelle Pi-Pfad besteht aus vier klar getrennten Schichten:

1. `GPIO backend`
   - direkter GPIO-Zugriff ueber `RPi.GPIO` auf Basis von `rpi-lgpio`
   - Fallback fuer Tests: `pinctrl`
2. `FrontPanelMonitor`
   - Taster-Polling in einem langlebigen Thread
   - GPIO-Flankeninterrupts fuer beide EC11-Kanaele mit `rpi-gpio`
   - entprellt Taster
   - dekodiert den `EC11`
   - erzeugt nur Hardwareevents
3. `Action Router`
   - uebersetzt Hardwareevents in fachliche Aktionen
   - erkennt auch die Dreifachtaste fuer den Buch-Loeschdialog
4. `Runtime Controller`
   - verarbeitet Aktionen
   - steuert Jobs, Audio, Buchkontext und Fehlerpfade

## Interrupts fuer den EC11, Polling fuer Taster

Der EC11 verwendet mit dem produktiven `rpi-gpio`-Backend Flankeninterrupts
auf Kanal A und B. Der Callback liest beide Pegel als gemeinsamen Snapshot
und fuehrt nur zeitkritische, nicht blockierende Arbeit aus:

- Quadraturdecoder aktualisieren
- threadsicheren Lautstaerke-Sollwert im Speicher veraendern
- normales Encoder-Event fuer Logging und Mixer-Synchronisation einreihen

Im Interrupt werden weder `amixer` noch Audio- oder andere Subprozesse
gestartet. Das verhindert lange Callback-Laufzeiten. Mechanische Taster
bleiben beim bewaehrten Polling mit Debounce. Falls nur `pinctrl` verfuegbar
ist, arbeitet auch der Encoder weiter per Polling; die Sollwertvariable wird
dann direkt im Monitor-Thread aktualisiert.

- Taster: Polling mit Debounce
- Encoder: Flankeninterrupt mit Quadratur-Dekodierung, Polling-Fallback
- Fachlogik: weiterhin nach Event-Uebersetzung; nur der atomare Sollwert wird
  bereits im Callback veraendert

## Polling-Fallback

Der Monitor arbeitet mit zwei Taktbereichen:

- Leerlauf: `2.0 ms`
- waehrend Encoder-Aktivitaet: `0.5 ms`
- `encoder_active_hold_ms`: `25 ms`
- Button-Debounce: `25 ms`

Diese schnellen Intervalle gelten fuer Taster-Snapshots und als
Encoder-Fallback. Bei aktivem GPIO-Interrupt werden Encoderpegel nicht
zusaetzlich im Pollingpfad dekodiert.

## Aktuell verdrahtete Bedienlogik

### `Start / Stop / NFC`

- startet den echten Lauf `capture -> Bildvorbereitung -> OCR -> page-ingest`
- stoppt einen laufenden foreground job
- stoppt eine laufende Seitenausgabe
- stoppt auch den reinen Heartbeat-Wartezustand

### `EC11`

- veraendert die Lautstaerke direkt
- funktioniert auch waehrend laufender Seiten- und Systemaudioausgabe wie
  `bing.wav`
- der Interrupt aktualisiert nur den Sollwert; Mixerzugriff, Logging und
  sonstige Subprozesse laufen weiterhin ausserhalb des Callbacks
- die eigentliche WAV-Wiedergabe fragt den Sollwert blockweise ab; Details zu
  Pufferung und Underrun-Schutz stehen in
  [CONTROL_RUNTIME_ARCHITECTURE.md](../docs/CONTROL_RUNTIME_ARCHITECTURE.md)

### `EC11-Taster`

- aktuell produktiv nur fuer den Buch-Loeschdialog genutzt

### Dreifachtaste

Die gleichzeitige Betaetigung aus:

- `Start / Stop / NFC`
- `Buch-Zusammenfassung`
- `Kapitel-/Letzte-Seiten-Zusammenfassung`

startet den Buch-Loeschdialog.

## Produktiv verdrahtete Summary-Tasten

### `Kapitel-/Letzte-Seiten-Zusammenfassung`

- spielt zuerst `kapitel_zusammenfassen`
- startet danach einen `bing`-Heartbeat bis die Audioausgabe startet
- zieht zunaechst neu abschliessbare Abschnitte nach und prueft danach den
  Text ab der persistenten offenen Abschnittsgrenze
- kombiniert offenen Text mit der letzten verfuegbaren
  Abschnittszusammenfassung zu einer temporaeren Rueckschau
- fasst vor dem ersten fertigen Abschnitt den offenen Text allein zusammen
- speichert diese temporaere Rueckschau nicht
- ohne offenen Text holt sie weiterhin die letzte verfuegbare
  Abschnittszusammenfassung und kann diese bei Bedarf ueber Gemini erzeugen
  oder aktualisieren

### `Buch-Zusammenfassung`

- spielt zuerst `buch_zusammenfassen`
- startet danach einen `bing`-Heartbeat bis die Audioausgabe startet
- erzeugt auf Basis aller vorhandenen Abschnittszusammenfassungen ein
  aktuelles "Was bisher geschah"

### Fehlender Summary-Inhalt

- nur wenn weder ein abgeschlossener Abschnitt noch offener Text vorliegt,
  spielt die Runtime `keine_zusammenfassung`

## Relevante Dateien

- [abr/hardware/control_panel.py](../abr/hardware/control_panel.py)
- [abr/control/frontpanel.py](../abr/control/frontpanel.py)
- [abr/control/runtime.py](../abr/control/runtime.py)
- [hardware/control_panel_service.py](../hardware/control_panel_service.py)

## Naechster sinnvoller Ausbau

Auf Ebene des Bedienpanels ist der naechste sinnvolle Schritt nicht mehr die
Grundverdrahtung, sondern Feinschliff und Betriebsreife:

1. Summary-Heartbeat und Fehlermeldungen mit echtem Pi-Betrieb weiter testen
2. Status-/Telemetry-Ereignisse fuer Abschnitt und Summary ergaenzen
3. spaeter `systemd`-Start fuer den Runtime-Dienst

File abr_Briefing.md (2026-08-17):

# Briefing für CODEX — Projekt „Accessible Book Reader (ABR)“

## Projektziel

Entwicklung eines Systems zum sehr einfachen Einscannen und Vorlesen von Büchern.

Das Buch wird **aufgeschlagen mit der bedruckten Seite nach unten** auf zwei geneigte Glasflächen gelegt. Die Konstruktion ähnelt einem Zelt („BookTent“). Unter jeder Glasfläche befindet sich später eine Kamera. Jede Seite wird separat fotografiert.

Ziel ist **nicht primär PDF-Erzeugung**, sondern:

1. zuverlässige Texterkennung (OCR)
2. Strukturierung des Textes
3. intelligente Seitenverknüpfung
4. Ausgabe als Sprache (Text-to-Speech)

Das System soll insbesondere für Belletristik funktionieren.

---

# Projektstrategie

Das größte Projektrisiko ist die Qualität der OCR-/Layout-Auswertung.

Deshalb wird zunächst **nur die Software-Pipeline entwickelt und getestet**, ohne spezielle Hardware.

## Phase 1: Software-Prototyp

Die ersten Tests erfolgen mit:

- einfachen Smartphone-Fotos
- simulierten Buchseiten
- manuell aufgenommenen Bildern

Erst wenn die OCR-/Strukturerkennung zuverlässig funktioniert, wird die Hardware entwickelt.

---

# Zielplattform

## Entwicklungsumgebung

- VS Code
- Python 3.11+
- Linux/macOS bevorzugt
- später Raspberry Pi 5

## Zielhardware (später)

- Raspberry Pi 5
- 2 × ESP32
- 2 × Kameramodule
- LED-Blitzbeleuchtung
- Lautsprecher

Die ESP32 sollen später nur:

- Kamera auslösen
- Blitz synchronisieren
- Bild übertragen

Die gesamte Bildauswertung läuft auf dem Raspberry Pi.

---

# Geometrie des späteren Geräts

## Mechanik

Das Buch liegt:

- aufgeschlagen
- mit den bedruckten Seiten nach unten
- auf zwei geneigten Glasflächen

Die Form entspricht einem Dach/Zelt.

## Typische Buchgröße

Optimierung auf Belletristik:

- Taschenbücher
- normale Hardcover

Empfohlene Glasfläche pro Seite:

- ca. 160 × 240 mm

---

# Anforderungen an die Software

# 1. Bildaufnahme

Das System soll zwei Bilder verarbeiten:

- linke Seite
- rechte Seite

Im Prototyp stammen diese Bilder zunächst von Smartphone-Fotos.

Später kommen sie von zwei Kameras.

---

# 2. Bildvorverarbeitung

Notwendige Schritte:

## Rotationserkennung

Das Buch kann in beiden Richtungen aufgelegt werden.

Die Software muss erkennen:

- welche Seite oben/unten ist
- ob 180° Rotation notwendig ist

## Bildoptimierung

- Graustufen
- Kontrastverbesserung
- adaptive Thresholds
- Schärfung
- Rauschreduzierung

Verwendbare Bibliotheken:

- OpenCV
- NumPy

---

# 3. OCR

Ziel:

- möglichst fehlerfreie Texterkennung
- zunächst deutschsprachige Bücher (später auch Englisch)
- Belletristik
- robuste Verarbeitung typischer Druckschrift

## OCR-Optionen

Die Architektur soll austauschbar sein.

Es sollen mindestens folgende OCR-Backends testbar sein:

### Option A — Tesseract

Vorteile:

- lokal
- stabil
- leichtgewichtig
- schnell

Nachteile:

- begrenzte Layoutanalyse

Bibliotheken:

- pytesseract
- tesseract-ocr-deu

---

### Option B — PaddleOCR

Vorteile:

- moderne Deep-Learning-OCR
- gute Layoutanalyse
- Orientation Detection
- Struktur-Erkennung

Soll bevorzugt getestet werden.

---

### Option C — docTR

Optional evaluieren.

---

# 4. Layout-/Strukturerkennung

Sehr wichtig.

Das System soll erkennen:

- Seitenzahlen
- Kapitelüberschriften
- Absätze
- Leerzeilen
- Kapitelwechsel

Ziel:

Die spätere Sprachausgabe soll natürlich wirken.

## Wichtiger Spezialfall

Ein Satz kann über zwei Seiten gehen.

Beispiel:

Seite 10 endet mit:

„Er öffnete langsam die Tür und“

Seite 11 beginnt mit:

„blickte in den dunklen Raum.“

Das System darf NICHT den unvollständigen Satz sprechen.

Stattdessen:

- Satz puffern
- nächste Seite abwarten
- Satz zusammenführen
- erst dann ausgeben

Dafür wird eine Textstruktur benötigt.

---

# 5. Satzsegmentierung

Benötigt:

- Satzende-Erkennung
- Erkennung unvollständiger Sätze
- Absatzgrenzen

Mögliche Bibliotheken:

- spaCy (deutsch)
- NLTK
- einfache heuristische Regeln

---

# 6. Seitenreihenfolge

Das System muss robust arbeiten bei:

- links/rechts vertauscht
- 180° Rotation
- unterschiedlicher Reihenfolge der Bilder

---

# 7. Text-to-Speech (TTS)

Der erkannte Text soll vorgelesen werden.

## Erste Zielsetzung

Lokale TTS-Lösung.

## Optionen

### Piper TTS (bevorzugt)

- gute Qualität
- lokal
- Raspberry Pi geeignet

### eSpeak NG

- fallback
- leichtgewichtig

---

# Softwarearchitektur

Die Architektur soll modular sein.

## Vorschlag

project/
│
├── input/
├── preprocessing/
├── orientation/
├── layout/
├── ocr/
├── text_logic/
├── tts/
├── tests/
└── run_fallback_pipeline.py

---

# Erwartete Pipeline

## Schritt 1

Lade zwei Bilder.

## Schritt 2

Vorverarbeitung.

## Schritt 3

Orientierung erkennen.

## Schritt 4

OCR durchführen.

## Schritt 5

Layout analysieren.

## Schritt 6

Textblöcke in Lesereihenfolge bringen.

## Schritt 7

Sätze zusammenführen.

## Schritt 8

Unvollständige Sätze puffern.

## Schritt 9

Text an TTS ausgeben.

---

# Ziel der ersten Entwicklungsphase

Zunächst KEINE GUI.

CLI genügt.

Beispiel:

```bash id="t2xrq9"
python run_fallback_pipeline.py left.jpg right.jpg
```

Ausgabe:

- erkannter Text
- Strukturinformationen
- erkannte Kapitel
- Debug-Bilder
- optionale Sprachausgabe

---

# Wichtige Entwicklungsziele

## Priorität 1

OCR-Qualität evaluieren.

## Priorität 2

Layout-/Struktur-Erkennung.

## Priorität 3

Satzfortsetzung über Seiten hinweg.

## Priorität 4

Robustheit gegen schlechte Bilder.

---

# Debug-/Analysefunktionen

Sehr wichtig.

Das System soll:

- Zwischenbilder speichern
- OCR-Konfidenzen anzeigen
- erkannte Layoutregionen visualisieren
- Rotation anzeigen
- erkannte Textblöcke markieren

---

# Empfohlene Bibliotheken

## Pflicht

- OpenCV
- NumPy
- Pillow

## OCR

- PaddleOCR
- pytesseract

## NLP

- spaCy (de_core_news_sm)

## TTS

- piper
- espeak-ng

---

# Anforderungen an CODEX

Zunächst soll der Code lokal auf einem Mac lauffähig sein. Später wird er dann auf den Raspberry Pi 5 portiert.

Bitte:

1. eine saubere modulare Python-Architektur erzeugen
2. austauschbare OCR-Backends vorsehen
3. Testbilder einfach integrierbar machen
4. Debugging stark unterstützen
5. zunächst auf lokale Verarbeitung optimieren
6. Raspberry-Pi-Kompatibilität beachten
7. keine unnötig komplexe Infrastruktur verwenden

---

# Erste konkrete Aufgabe für CODEX

Implementiere einen ersten Prototypen mit:

- Bild laden
- Vorverarbeitung
- Rotationserkennung
- OCR
- einfache Absatz-/Satzsegmentierung
- Konsolenausgabe
- optionaler TTS-Ausgabe

Nutze zunächst PaddleOCR und OpenCV.

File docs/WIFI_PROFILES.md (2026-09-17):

# Multiple Wi-Fi Profiles

Deutsche Fassung: [Mehrere WLAN-Profile](../docs_DE/WIFI_PROFILES.md)

The Raspberry Pi uses NetworkManager for Wi-Fi connections. The ABR tool
`abr.wifi_profiles` therefore does not maintain a separate password file; it
works with NetworkManager's protected connection profiles.

Practically verified as of `2026-08-03`:

- switching from the local router to an iPhone hotspot works
- switching back is also possible through a Raspberry Pi Connect session
- adding a profile is separate from switching connections, so the active SSH
  session remains available while saving it
- at boot and after connection loss, NetworkManager can automatically choose
  from all stored, reachable profiles

## Listing and Adding Profiles

```bash
cd ~/src/abr
sudo .venv/bin/python -m abr.wifi_profiles list
sudo .venv/bin/python -m abr.wifi_profiles add PROFILE_NAME ACTUAL_SSID
```

`add` first prompts interactively for the Wi-Fi password and then creates the
complete NetworkManager profile. Credentials are therefore available before
activation can interrupt the existing SSH connection. The password is not
stored in shell history or in the repository. Profile name and SSID may be
different. Quote names containing spaces.

Important: Names in this guide are placeholders. Run commands individually
with the actual SSID; do not paste an entire example block unchanged. `add`
saves the profile without changing the active connection. Immediate
activation is possible with `--activate`, but may interrupt an SSH session.

An existing Wi-Fi connection already stored by NetworkManager does not need
to be recreated. Prepare every existing profile for automatic selection once:

```bash
sudo .venv/bin/python -m abr.wifi_profiles configure
```

This sets `connection.autoconnect=yes` and
`connection.autoconnect-retries=1` so one broken profile does not monopolize
automatic activation. Install the recovery service below for continuous
retries across saved profiles; `configure` alone does not install it.

## Checking Profile Name and SSID

Profile name and SSID are not necessarily identical. The ABR tool displays
profile names:

```bash
sudo .venv/bin/python -m abr.wifi_profiles list
```

NetworkManager displays the SSID of a specific profile:

```bash
nmcli -g 802-11-wireless.ssid connection show "Example WiFi"
```

List profile names and types (query each SSID separately as above):

```bash
nmcli -f NAME,TYPE connection show
```

For `switch`, copy the profile name from `abr.wifi_profiles list` exactly.
The UUID shown there can be used instead.

## Switching Manually

```bash
sudo .venv/bin/python -m abr.wifi_profiles switch Mobile
```

Alternatively, trigger automatic selection from all stored profiles
immediately:

```bash
sudo .venv/bin/python -m abr.wifi_profiles auto
```

Within a detected SSH session, `switch`, `auto`, `watch`, and `add --activate`
are rejected by default. Plain `add` remains allowed. Install and check the
recovery service below before switching without a keyboard and monitor.
To allow the switch over SSH, place the override before the subcommand:

```bash
sudo .venv/bin/python -m abr.wifi_profiles --allow-ssh-disconnect switch Mobile
```

The ABR runtime continues independently of SSH as a systemd service.

If no keyboard or monitor is connected to the Pi, use this sequence with the recovery service installed:

1. Save the new profile over SSH using `add`; the active connection remains
   unchanged.
2. Verify the profile name and UUID with `list`.
3. Enable the target Wi-Fi network.
4. Deliberately switch with
   `--allow-ssh-disconnect switch PROFILE_NAME`.
5. Connect the other computer to the target network and reconnect to the Pi
   through `abr.local`, its IP address, or Raspberry Pi Connect.
6. To switch back, use the exact displayed name of the local profile.

If several networks are reachable at once, assign priorities while adding
them:

```bash
sudo .venv/bin/python -m abr.wifi_profiles add Home MyWiFi --priority 20
sudo .venv/bin/python -m abr.wifi_profiles add Mobile MyHotspot --priority 10
```

## Continuous Recovery Service

Install once, including on devices using the previous configuration:

```bash
cd ~/src/abr
sudo deploy/install_wifi_autoconnect.sh
```

This configures profiles and installs/starts `abr-wifi-autoconnect.service`.
It runs as root to activate system profiles without an interactive permission
agent, starts at boot, and is independent of SSH and the reader service.

It checks `wlan0`, waiting ten seconds between iterations; scans and
activation attempts can extend each iteration. An established Wi-Fi connection is left
alone, including networks without Internet access. When disconnected, it
requests a scan and tries saved profiles in stable UUID order, cycling forever.
A failed profile does not prevent later profiles from being tried. NetworkManager's
own automatic selection still uses configured priorities. New/deleted profiles
are picked up automatically, and unknown open networks are never created.

Each activation command waits up to 45 seconds. Existing/manual activation
attempts get up to 120 seconds before recovery tries the next profile; an
nmcli timeout does not necessarily cancel activation inside NetworkManager.
Recovery resumes after failed manual switches and subsequent connection loss.
NetworkManager errors are retried, and systemd restarts the monitor if it exits.

An enabled, managed Wi-Fi adapter and a reachable saved network with valid
credentials are required. Missing/blocked adapters are checked repeatedly;
radio and management restrictions are not overridden. This checks the Wi-Fi
connection, not Internet availability.

```bash
sudo systemctl status abr-wifi-autoconnect.service --no-pager
sudo journalctl -u abr-wifi-autoconnect.service -n 30 -f
```

On-device validation: turn the hotspot off and back on, and verify reconnection
without SSH intervention. Also test a failing saved profile alongside a working
one. Automated tests simulate these cases; actual radio and DHCP behavior still
requires a Raspberry Pi test.

## Updating an Existing Installation

After transferring the updated code to the Pi, rerun the installer. A Git
update alone does not install/update the systemd unit. The installer restarts
the monitor, which preserves an established connection. The control-panel
service does not need to be stopped.

```bash
cd ~/src/abr
sudo deploy/install_wifi_autoconnect.sh
systemctl is-enabled abr-wifi-autoconnect.service
systemctl is-active abr-wifi-autoconnect.service
```

Expect `enabled` and `active`. `--allow-ssh-disconnect` neither installs a
service nor implements rollback; continued recovery requires the installed
monitor.

## Diagnostics

```bash
nmcli device status
nmcli radio wifi
sudo .venv/bin/python -m abr.wifi_profiles list
sudo journalctl -u abr-wifi-autoconnect.service -b -n 100 --no-pager
sudo journalctl -u NetworkManager.service -b -n 100 --no-pager
```

| Log / status | Meaning / next step |
|---|---|
| `Keine gespeicherten WLAN-Profile` | Save at least one profile using `add`. |
| `WLAN-Geraet nicht bereit` | Check the adapter, radio state and NetworkManager management. |
| `WLAN-Verbindung fehlgeschlagen` | Check SSID, password and range; other profiles will still be tried. |
| `WLAN verbunden` | Wi-Fi is connected. Lack of Internet alone does not trigger switching. |
| Service `inactive` / `failed` | Read the service log and rerun the installer. |

A full pass through several profiles can take several minutes. If no saved
network is reachable, the Pi remains offline and continues trying. To regain
SSH access, the Mac must be able to reach the connected network using
`abr.local` or the current IP address.

## Headless Device Test

1. Install the monitor and verify `enabled` / `active`.
2. Save two reachable networks with valid credentials.
3. Turn off the connected network; verify automatic connection to the other.
   Move the Mac to that network if necessary for SSH.
4. Turn off both networks, wait, then enable one again; verify reconnection
   even after multiple unsuccessful search rounds.
5. Repeat to verify recovery after subsequent connection loss.
6. Optionally activate a separate test profile with an incorrect password;
   a reachable valid profile must still be tried afterwards.
7. Reboot and verify automatic startup of the monitor and Wi-Fi connection.

As of 2026-09-17, 24 automated Wi-Fi tests pass. The new monitor has not yet
been validated on actual Raspberry Pi hardware.

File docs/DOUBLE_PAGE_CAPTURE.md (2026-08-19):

# Double-Page Capture

Last reviewed: `2026-08-19`

Deutsche Fassung: [Doppelseitenaufnahme](../docs_DE/DOUBLE_PAGE_CAPTURE.md)

## Purpose

This tool is the first production adapter between the physical Raspberry Pi
cameras and the existing OCR/TTS pipeline.

It implements `Sprint 1`:

- capture two real camera images
- apply the existing remaps automatically
- create a standardized `case` directory containing `left.jpg` and
  `right.jpg`
- then create an OCR directory containing `left.png`, `right.png`, and
  `manifest.json`
- then create OCR preprocessing images below `debug/page_1` and `page_2`
- enable the LED channel assigned to each page only while that page is being
  captured

The current debugging phase also provides a simple raw-image mode:

- capture only the two raw images
- default to the resolution stored in the remap file
- store them at the stable path `captures/latest/raw/` for quick download to
  the Mac

The currently preferred OCR path subsequently processes the generated `ocr`
directory with `hardware/run_rapidocr.py`.

OCR preprocessing is also available as a separate tool and is used internally
by `capture_double_page`. `run_fallback_pipeline.py` now processes prepared
OCR images only; for quick runs on the Pi, the lightweight
`hardware/run_rapidocr.py` wrapper is currently preferred.

Important behavior of the production front-panel path:

- `capture_double_page.py` initially captures camera 0 as `case/left.jpg` and
  camera 1 as `case/right.jpg` using the normal assignment.
- After capture, the runtime fetches the result of the previously started
  PN5180 query to identify the book. Reader position is not used for page
  orientation.
- The runtime prepares `case/left.jpg` in memory, detects three long text
  lines, and uses RapidOCR's angle classifier to decide between upright and
  upside down.
- Upright text keeps the two `case` files assigned; upside-down text swaps
  `case/left.jpg` and `case/right.jpg`.
- The runtime then rotates `case/right.jpg` once by `180` degrees.
- In the NFC runtime path, shared OCR preprocessing does not rotate either
  page again.
- Reliable orientation results update the per-book marker. If the page is
  empty, text-poor, or ambiguous, the last stored orientation is used.

## Files

- Module: [abr/hardware/double_page_capture.py](../abr/hardware/double_page_capture.py)
- Wrapper: [hardware/capture_double_page.py](../hardware/capture_double_page.py)
- Shared preprocessing module: [abr/preprocessing/enhance_for_ocr.py](../abr/preprocessing/enhance_for_ocr.py)
- CLI wrapper for isolated preprocessing: [hardware/enhance_for_ocr.py](../hardware/enhance_for_ocr.py)
- Lightweight RapidOCR wrapper: [hardware/run_rapidocr.py](../hardware/run_rapidocr.py)

## Prerequisites on the Pi

- both cameras are detected by `rpicam-hello --list-cameras`
- `rpicam-still` is available
- the project virtual environment is installed
- `opencv-contrib-python` and `numpy` are installed in the virtual environment
- the remaps are available at:
  - `calibration/out/cam0_planar.npz`
  - `calibration/out/cam1_planar.npz`

Important:

- this tool does **not** require `Picamera2` for capture
- it invokes `rpicam-still` for capture
- without an explicit exposure time, `rpicam-still` retains its normal
  automatic behavior
- without an explicit `--gain`, gain control also remains automatic
- rectification then uses the existing
  [calibration/apply_saved_remap.py](../calibration/apply_saved_remap.py)

## Standard Output

One run creates the following structure below `captures/<session-name>/`:

```text
captures/
  scan_20260626_153000/
    raw/
      cam0_raw.jpg
      cam1_raw.jpg
    rectified/
      cam0_rectified.jpg
      cam1_rectified.jpg
    case/
      left.jpg
      right.jpg
    ocr/
      left.png
      right.png
      manifest.json
    debug/
      page_1/
        01_gray.png
        02_enhanced.png
        03_sharpened.png
        04_binary.png
      page_2/
        01_gray.png
        02_enhanced.png
        03_sharpened.png
        04_binary.png
    metadata.json
```

Meaning:

- `raw/`: raw camera images directly from `rpicam-still`
- `rectified/`: images rectified with the remap
- `case/`: rectified pages before final OCR preparation
- `ocr/`: final input for `python hardware/run_rapidocr.py --ocr-dir ...`
- `debug/`: inspectable OCR preprocessing for both pages
- `metadata.json`: camera indices, remaps, invoked commands, and runtime
  metrics

A stable mirror of the latest run is also always created under
`captures/latest/`.

This path is also the default source for the camera test server's review mode.

## Typical Run on the Pi

From the project's virtual environment:

```bash
cd ~/src/abr
source .venv/bin/activate
python hardware/capture_double_page.py --no-denoise
```

The tool defaults to:

- left page: camera `0`
- right page: camera `1`
- `LED-left` on `BCM12` during left-page capture
- `LED-right` on `BCM13` during right-page capture
- remaps:
  - `calibration/out/cam0_planar.npz`
  - `calibration/out/cam1_planar.npz`

The session automatically receives a timestamped name such as
`scan_20260626_153000`.

Measured Raspberry Pi runtime on `2026-07-01` for this mode:

- total capture: approximately `3.85s`
- total rectification: approximately `3.86s`
- total OCR preprocessing with `--no-denoise`: approximately `2.77s`
- complete capture path through `ocr/*.png`: approximately `10.9s`

For comparison:

- the same preprocessing stage previously took approximately `15.5s` with
  denoising enabled
- `--no-denoise` is therefore the currently preferred setting

## Step-by-Step Raw-Image Test

For the current image-quality check, capture raw images first:

```bash
cd ~/src/abr
source .venv/bin/activate
python -m abr.hardware.double_page_capture --raw-only
```

Important:

- without `--width/--height`, the tool now defaults to the calibration
  resolution stored in each remap
- this should select the full-resolution path for the current setup
- the resulting images are stored at:
  - `captures/latest/raw/cam0_raw.jpg`
  - `captures/latest/raw/cam1_raw.jpg`

These two files are the preferred first download path to the Mac.

## Step-by-Step Rectification Test

Once the raw images look correct, rectify the existing images without
capturing them again:

```bash
cd ~/src/abr
source .venv/bin/activate
python -m abr.hardware.double_page_rectify
```

Alternatively, use the wrapper:

```bash
python hardware/rectify_double_page.py
```

The default path:

- reads from `captures/latest/raw/`
- writes to:
  - `captures/latest/rectified/`
  - `captures/latest/case/`
  - `captures/latest/ocr/`
  - `captures/latest/debug/`

Expected files:

```text
captures/latest/rectified/cam0_rectified.jpg
captures/latest/rectified/cam1_rectified.jpg
captures/latest/case/left.jpg
captures/latest/case/right.jpg
captures/latest/ocr/left.png
captures/latest/ocr/right.png
captures/latest/ocr/manifest.json
captures/latest/debug/page_1/02_enhanced.png
captures/latest/debug/page_2/02_enhanced.png
captures/latest/metadata.json
```

These paths make it easy to copy the rectified images back to the Mac.

If one page is upside down after rectification, a fixed post-rotation can be
specified per page.

Typical case for the current setup:

```bash
python -m abr.hardware.double_page_rectify --right-rotate 180
```

This rotates only the right page by `180` degrees after rectification and
before writing `case/right.jpg`.

This manual parameter is intended for isolated capture and rectification
tests. In the production front-panel path, the right page is rotated
automatically after OCR-based assignment.

## Current Follow-Up Command

After a successful capture, the currently preferred OCR run is:

```bash
cd ~/src/abr
source .venv/bin/activate
python hardware/run_rapidocr.py \
  --ocr-dir captures/latest/ocr \
  --output-dir runs/latest_rapidocr \
  --orientation-mode off \
  --overlay
```

Important for this isolated wrapper command:

- the wrapper still provides optional additional orientation detection
- it is currently **not** part of the preferred standard path
- it presently costs several seconds per page and is intended for separate
  optimization later

This does not describe the production front-panel orientation probe. The
runtime performs one fast, shared three-line classification before preparing
and recognizing the pages, so it does not OCR each complete page twice.

## Important Options

Fixed session name:

```bash
python hardware/capture_double_page.py --session-name first_book_scan
```

Different camera assignment:

```bash
python hardware/capture_double_page.py --left-camera 1 --right-camera 0
```

Different remaps:

```bash
python hardware/capture_double_page.py \
  --left-remap calibration/out/cam1_planar.npz \
  --right-remap calibration/out/cam0_planar.npz
```

Higher JPEG quality or a longer timeout:

```bash
python hardware/capture_double_page.py \
  --jpeg-quality 98 \
  --timeout-ms 2000
```

Shared manual exposure time for both cameras:

```bash
python hardware/capture_double_page.py \
  --shutter-us 8000
```

Notes:

- `--shutter-us` sets the exposure time in microseconds for both pages
- without `--shutter-us`, automatic exposure remains active

Shared manual gain for both cameras:

```bash
python hardware/capture_double_page.py \
  --gain 1.5
```

Fully manual baseline for both cameras:

```bash
python hardware/capture_double_page.py \
  --shutter-us 8000 \
  --gain 1.5
```

Notes:

- `--gain` sets analog gain for both pages
- without `--gain`, automatic gain control remains active

Run OCR preprocessing in isolation on an existing `case` directory:

```bash
python hardware/enhance_for_ocr.py \
  --case-dir captures/latest/case \
  --ocr-dir captures/latest/ocr \
  --debug-dir captures/latest/debug
```

This is the same preprocessing path used internally by
`capture_double_page`.

Capture raw images only, without rectification or case generation:

```bash
python -m abr.hardware.double_page_capture --raw-only
```

Rectify a specific session directory instead of `captures/latest/`:

```bash
python -m abr.hardware.double_page_rectify --session-dir captures/scan_20260626_184412
```

## Continuing Through the Pipeline

After a successful capture, pass the generated `ocr` directory to the
existing OCR/TTS pipeline.

Example using the complete fallback path:

```bash
python run_fallback_pipeline.py \
  --case-dir captures/scan_20260626_153000/ocr \
  --ocr-backend rapidocr \
  --output-dir runs/scan_20260626_153000
```

For a direct OCR comparison, the same prepared `ocr` directory can be
processed with Tesseract:

```bash
python run_fallback_pipeline.py \
  --case-dir captures/scan_20260626_153000/ocr \
  --ocr-backend tesseract \
  --output-dir runs/scan_20260626_153000_tesseract
```

Or with live TTS:

```bash
export GOOGLE_CLOUD_QUOTA_PROJECT=YOUR_PROJECT_ID
python run_fallback_pipeline.py \
  --case-dir captures/scan_20260626_153000/ocr \
  --ocr-backend rapidocr \
  --tts-backend google \
  --google-tts-voice-name de-DE-Standard-H \
  --google-tts-language-code de-DE \
  --tts-speed 0.9 \
  --speak \
  --live-tts-max-chars 700 \
  --no-debug-artifacts \
  --output-dir runs/scan_20260626_153000_live
```

## Sprint 1 Acceptance Criteria

`Sprint 1` is successful when:

- `hardware/capture_double_page.py` creates two raw images
- both raw images are rectified automatically
- `case/left.jpg` and `case/right.jpg` are created
- `ocr/left.png` and `ocr/right.png` are created
- `python run_fallback_pipeline.py --case-dir ...` runs on the resulting
  `ocr` directory

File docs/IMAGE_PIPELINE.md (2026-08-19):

# Image Pipeline

Last reviewed: `2026-08-19`

Deutsche Fassung: [Bildpipeline](../docs_DE/IMAGE_PIPELINE.md)

## Purpose

This document defines which image operations belong to each processing stage
and identifies the currently preferred path for the Raspberry Pi scanner.

The responsibilities are separated as follows:

- `capture_double_page`: capture, rectify, and prepare OCR images
- `enhance_for_ocr`: isolated image enhancement for existing `case` images
- `run_rapidocr.py`: lightweight OCR run for `ocr/left.png` and
  `ocr/right.png`
- `run_fallback_pipeline.py`: complete comparison and TTS path, but not the
  currently preferred runtime path

`run_fallback_pipeline.py` no longer performs **any** image optimization.

Important context:

- the current production path runs through `hardware/control_panel_service.py`
- it captures both pages first and then processes the left page before the
  right page
- in this path, `capture_double_page.py` runs with `--skip-enhance`
- before per-page preparation, the runtime prepares the raw left case image
  in memory and classifies three detected text lines as `0` or `180` degrees
- it applies the resulting shared page assignment once, then prepares the OCR
  image separately for each page

## Manual Reference Path on the Pi

The manual reference path on the Pi remains:

1. `python hardware/capture_double_page.py --no-denoise`
2. `python hardware/run_rapidocr.py --ocr-dir captures/latest/ocr --output-dir runs/latest_rapidocr --orientation-mode off --overlay`

Rationale for this isolated manual path:

- compared with the previous preprocessing path, `--no-denoise` saves
  approximately `12-13s` per spread
- the lightweight RapidOCR wrapper writes `left.txt` early and then writes
  `right.txt`
- the wrapper's older full per-page orientation comparison is too expensive
  and is therefore not enabled by default

The production front-panel path is different: it uses the fast three-line
RapidOCR angle classifier once per spread before normal OCR. It stores a
reliable result per book and falls back to that marker on text-poor pages.

Measured Raspberry Pi performance on `2026-07-01`:

- `capture_double_page`, including rectification and OCR preprocessing:
  approximately `10.9s`
- OCR preprocessing with `--no-denoise` within that run: approximately `2.8s`
- lightweight RapidOCR wrapper with its older simple orientation comparison:
  approximately
  `24.2s`
- for this wrapper, the recommendation remains `--orientation-mode off`;
  production orientation is handled by the separate shared three-line probe

## 1. `capture_double_page`

Wrapper:

- [hardware/capture_double_page.py](../hardware/capture_double_page.py)

Implementation:

- [abr/hardware/double_page_capture.py](../abr/hardware/double_page_capture.py)

Internal sequence:

1. Capture the left raw image.
2. Capture the right raw image.
3. Rectify both raw images using the saved remaps.
4. Write `case/left.jpg` and `case/right.jpg`.
5. Apply the enhancement routine to the `case` directory.
6. Produce OCR-ready input images and debug stages.
7. Publish `captures/latest/` as the latest stable run.

Input:

- cameras `cam0` and `cam1`
- remaps `calibration/out/cam0_planar.npz` and
  `calibration/out/cam1_planar.npz`

Output below `captures/<session>/`:

```text
raw/
  cam0_raw.jpg
  cam1_raw.jpg
rectified/
  cam0_rectified.jpg
  cam1_rectified.jpg
case/
  left.jpg
  right.jpg
ocr/
  left.png
  right.png
  manifest.json
debug/
  page_1/
    01_gray.png
    02_enhanced.png
    03_sharpened.png
    04_binary.png
  page_2/
    01_gray.png
    02_enhanced.png
    03_sharpened.png
    04_binary.png
metadata.json
```

Meaning:

- `case/left.jpg`, `case/right.jpg`: rectified page images
- `ocr/left.png`, `ocr/right.png`: final OCR input for `run_rapidocr.py` or,
  alternatively, `run_fallback_pipeline.py`
- `ocr/manifest.json`: mapping between OCR files and source images, including
  preprocessing timings
- `debug/page_x/...`: inspectable preprocessing stages
- `metadata.json`: capture, rectification, and enhancement timings for the
  complete run

Currently recommended command on the Pi:

```bash
cd ~/src/abr
source .venv/bin/activate
python hardware/capture_double_page.py --no-denoise
```

## 2. `enhance_for_ocr`

Wrapper:

- [hardware/enhance_for_ocr.py](../hardware/enhance_for_ocr.py)

Implementation:

- [abr/preprocessing/enhance_for_ocr.py](../abr/preprocessing/enhance_for_ocr.py)

Purpose:

- bring existing `case` images to the same OCR-ready state produced by
  `capture_double_page`

Input:

- `case/left.jpg`
- `case/right.jpg`

Output:

- `ocr/left.png`
- `ocr/right.png`
- `ocr/manifest.json`
- `debug/page_1/01_gray.png`
- `debug/page_1/02_enhanced.png`
- `debug/page_1/03_sharpened.png`
- `debug/page_1/04_binary.png`
- `debug/page_2/01_gray.png`
- `debug/page_2/02_enhanced.png`
- `debug/page_2/03_sharpened.png`
- `debug/page_2/04_binary.png`

Important option:

- `--no-denoise`: disables the former main performance bottleneck,
  `fastNlMeansDenoising`

Example:

```bash
python hardware/enhance_for_ocr.py \
  --case-dir testdata/roman_001 \
  --ocr-dir runs/roman_001_prepare/ocr \
  --debug-dir runs/roman_001_prepare/debug \
  --no-denoise
```

## 3. `run_rapidocr.py`

Wrapper:

- [hardware/run_rapidocr.py](../hardware/run_rapidocr.py)

Implementation:

- [abr/capture_ocr.py](../abr/capture_ocr.py)

Purpose:

- recognize the prepared `ocr/left.png` and `ocr/right.png` with `RapidOCR`
- write text early, one page at a time
- optionally create OCR overlays for the review server
- record timings per page and processing stage

Input:

- a prepared OCR directory containing:
  - `left.png`
  - `right.png`
  - `manifest.json`

Wrapper sequence:

1. Load the prepared OCR images.
2. Optionally check simple 0/180-degree orientation.
3. Run OCR for each page.
4. Write and flush `left.txt` immediately.
5. Write `right.txt` afterward.
6. Produce `report.json` and, optionally, `06_ocr_overlay.png`.

Currently recommended command:

```bash
python hardware/run_rapidocr.py \
  --ocr-dir captures/latest/ocr \
  --output-dir runs/latest_rapidocr \
  --orientation-mode off \
  --overlay
```

Output below `runs/<run>/`:

```text
left.txt
right.txt
report.json
debug/
  page_1/
    06_ocr_overlay.png
  page_2/
    06_ocr_overlay.png
```

Important decision:

- `--orientation-mode simple` remains available as an experimental option
- the currently preferred default is **`--orientation-mode off`**
- this legacy comparison adds several seconds per page and is not used by the
  production runtime

These options control the wrapper's older per-page 0/180 comparison. They do
not disable the production runtime's shared three-line orientation probe.

## 4. `run_fallback_pipeline.py`

Entry points:

- [run_fallback_pipeline.py](../run_fallback_pipeline.py)
- [abr/cli.py](../abr/cli.py)
- [abr/pipeline.py](../abr/pipeline.py)

Input:

- a prepared OCR directory containing:
  - `left.png`
  - `right.png`
  - `manifest.json`

Typical sources:

- `captures/<session>/ocr/`
- `captures/latest/ocr/`
- `runs/<name>_prepare/ocr/`

`run_fallback_pipeline.py` performs the following steps:

1. Load OCR-ready `left.png` and `right.png`.
2. Run OCR.
3. Build layout and paragraphs.
4. Write reading text and the report.
5. Optionally produce TTS output.

`run_fallback_pipeline.py` no longer performs:

- rectification
- contrast enhancement
- sharpening
- binarization

It remains useful for:

- TTS tests
- comparison runs against the lightweight wrapper
- layout, segmentation, and reading-flow logic

Example:

```bash
python run_fallback_pipeline.py \
  --case-dir runs/roman_001_prepare/ocr \
  --ocr-backend rapidocr \
  --output-dir runs/roman_001
```

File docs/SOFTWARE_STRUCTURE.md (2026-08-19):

# Software Structure

Last reviewed: `2026-08-18`

Deutsche Fassung: [Softwarestruktur](../docs_DE/SOFTWARE_STRUCTURE.md)

## Purpose

This document explains the current repository structure and maps the principal
modules to the production device path, development tools, and persistent data.

## Runtime Paths

### Production Device Path

The canonical Raspberry Pi entry point is
[hardware/control_panel_service.py](../hardware/control_panel_service.py),
started continuously by the systemd service.

The main flow is:

```text
front-panel event
  -> NFC query through the Pico gateway
  -> capture both cameras
  -> resolve the book from NFC and classify page orientation from text lines
  -> prepare, recognize, ingest, and read the left page
  -> process the right page in parallel
  -> update section assembly and summaries
```

### Development and Comparison Path

[run_fallback_pipeline.py](../run_fallback_pipeline.py) runs a complete but
non-production OCR/TTS comparison through `abr.cli` and `abr.pipeline`. It is
retained for backend comparisons, layout tests, and isolated experiments. It
is not the finished device runtime.

## The `abr` Python Package

### `abr/control`: Device Coordination

- [runtime.py](../abr/control/runtime.py)
  - `RuntimeController`, `ForegroundJobManager`, and `PageAudioPlayer`
  - start/stop semantics, heartbeat, and book deletion dialog
  - capture, OCR, ingest, summary, and audio orchestration
  - protection against repeated and backward page scans
- [frontpanel.py](../abr/control/frontpanel.py)
  - long-lived monitor, debounce, and EC11 quadrature decoding
  - hardware events and application-action routing
- [audio_volume.py](../abr/control/audio_volume.py)
  - ten volume levels from 20 to 100 percent
  - thread-safe target value and optional ALSA mixer synchronization
- [artifact_cleanup.py](../abr/control/artifact_cleanup.py)
  - controlled cleanup of short-lived capture and OCR artifacts

### `abr/hardware`: Raspberry Pi Adapters

- [control_panel.py](../abr/hardware/control_panel.py)
  - BCM assignments and the `rpi-gpio`/`pinctrl` backends
- [led_control.py](../abr/hardware/led_control.py)
  - separate lighting for left and right capture
- [double_page_capture.py](../abr/hardware/double_page_capture.py)
  - capture through `rpicam-still`, remapping, and session layout
- [double_page_rectify.py](../abr/hardware/double_page_rectify.py)
  - rectify previously captured raw images
- [pico_gateway_client.py](../abr/hardware/pico_gateway_client.py)
  - shared UART client for the Raspberry Pi Pico gateway
- [nfc_gateway.py](../abr/hardware/nfc_gateway.py)
  - reader status and ISO14443A/ISO15693 book identification
  - two-stage `STATUS_START` and `STATUS_FETCH` query

The Raspberry Pi contains no direct PN5180 or PN532 driver. Readers connect
only to the Pico; Pi software sees only the UART protocol.

### `abr/book`: Persistent Book Domain

- [models.py](../abr/book/models.py)
  - `BookRecord`, `ScanRecord`, `PageRecord`, `ChapterRecord`,
    `SummaryRecord`, and chapter markers
- [store.py](../abr/book/store.py)
  - atomic JSON and text storage below `library/<tag_id>/`
  - preferred ISO14443A IDs, ISO15693 aliases, and direct ISO15693 book IDs
  - persistent orientation/runtime state and language validation
- [session.py](../abr/book/session.py)
  - tag-to-book-session resolution
- [page_ingestor.py](../abr/book/page_ingestor.py)
  - converts OCR reports into semantic `PageRecord`s
  - page numbers, chapter markers, paragraphs, and page transitions
  - separate `clean_text` and `speak_text` fields
  - language-aware TTS preparation
- [chapter_assembler.py](../abr/book/chapter_assembler.py)
  - synthetic sections in a 10-to-20-page window
  - persistent boundaries, including offsets within a page
  - open section text for temporary recaps
- [summary_manager.py](../abr/book/summary_manager.py)
  - Gemini backend for section and book summaries
  - length policy, cache validation, language, and source fingerprint
  - non-persistent summary of the open section
  - optional asynchronous `SummaryService`

See [BOOK_RUNTIME_DATA_ARCHITECTURE.md](BOOK_RUNTIME_DATA_ARCHITECTURE.md) for
the complete data layout.

### Capture, Image Preparation, and OCR

- [capture_ocr.py](../abr/capture_ocr.py)
  - lightweight regular and incremental OCR execution
  - selection and voting of three RapidOCR angle-classifier line crops
  - writes reports and optional overlays
- `abr/preprocessing/`
  - `enhance_for_ocr.py`: production per-page preparation
  - `processor.py`: general preprocessing stages
- `abr/orientation/detector.py`
  - older optional 0/180-degree comparison for non-production pipelines
- `abr/ocr/`
  - `base.py` and `factory.py`: backend interface and selection
  - `rapidocr_backend.py`: production local OCR plus text-line detection and
    `0`/`180` angle classification
  - `tesseract_backend.py`: fallback and comparison
  - `paddle_backend.py`: experimental comparison path
- `abr/layout/basic.py`: basic paragraph and layout blocks
- `abr/input/loader.py`: prepared pipeline input loading
- `abr/debug/`: debug artifacts and visualizations
- `abr/reporting.py`: serialized pipeline reports and timings

The stage boundaries are documented in [IMAGE_PIPELINE.md](IMAGE_PIPELINE.md).

### Text Logic

- [ocr_cleanup.py](../abr/text_logic/ocr_cleanup.py)
  - hyphenation and common OCR artifacts
  - letter-spaced words and all-uppercase headings
  - German pronunciation exceptions `Dr.` → `Doktor` and
    `Notre-Dame` → `Notre Damm`
- [segmenter.py](../abr/text_logic/segmenter.py)
  - sentence and TTS segmentation
- [reading_order.py](../abr/text_logic/reading_order.py)
  - reading order of detected regions

### TTS and Audio Playback

- `abr/tts/base.py`: shared TTS interface
- `abr/tts/command_backend.py`
  - eSpeak, macOS `say`, Piper, OpenAI, and ElevenLabs
  - Google Standard, Neural2, and Gemini Flash TTS
- [audio_playback.py](../abr/audio_playback.py)
  - shared process-wide playback lock
  - block-wise PCM streaming to `aplay`
  - dynamic software volume and underrun protection
- [system_audio.py](../abr/system_audio.py)
  - serial queue for pre-generated system prompts

Production page playback currently uses `google-standard-enhanced`. Its
renderer creates chapter, sentence, paragraph, and dialogue pauses as SSML at
runtime; these annotations are not persisted in book data.

### Language and Google Authentication

- [language_config.py](../abr/language_config.py)
  - immutable German and U.S. English profiles
  - atomic selection in `~/.config/abr/device.json`
- [google_cloud_auth.py](../abr/google_cloud_auth.py)
  - shared ADC access and token, project, and quota-project resolution

Language is propagated through capture, OCR, book, section, summary, and TTS.
Mixed-language data is rejected. See
[LANGUAGE_PROFILES.md](LANGUAGE_PROFILES.md).

### Operational Features

- [wifi_profiles.py](../abr/wifi_profiles.py)
  - NetworkManager profiles, priorities, switching, and persistent autoconnect
- [remote_mail.py](../abr/remote_mail.py), `remote_mail_download.py`, and
  `remote_mail_upload.py`
  - optional validated SMTP/IMAP file transfer
- [usage_statistics.py](../abr/usage_statistics.py)
  - per-book page, audio, and summary counters
- [usage_report.py](../abr/usage_report.py)
  - daily report, e-mail delivery, and archiving

Personal configuration exists only below `~/.config/abr/`, in
`~/.config/gcloud/`, or in NetworkManager, never in the repository.
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

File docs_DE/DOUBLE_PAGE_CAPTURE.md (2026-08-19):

# Double Page Capture

Stand: `2026-08-19`

## Zweck

Dieses Werkzeug ist der erste produktive Adapter zwischen den realen Pi-Kameras
und der bestehenden OCR-/TTS-Pipeline.

Es erledigt genau `Sprint 1`:

- zwei reale Kamerabilder aufnehmen
- die vorhandenen Remaps automatisch anwenden
- einen standardisierten `case`-Ordner mit `left.jpg` und `right.jpg` erzeugen
- direkt danach einen OCR-Ordner mit `left.png`, `right.png` und `manifest.json` erzeugen
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

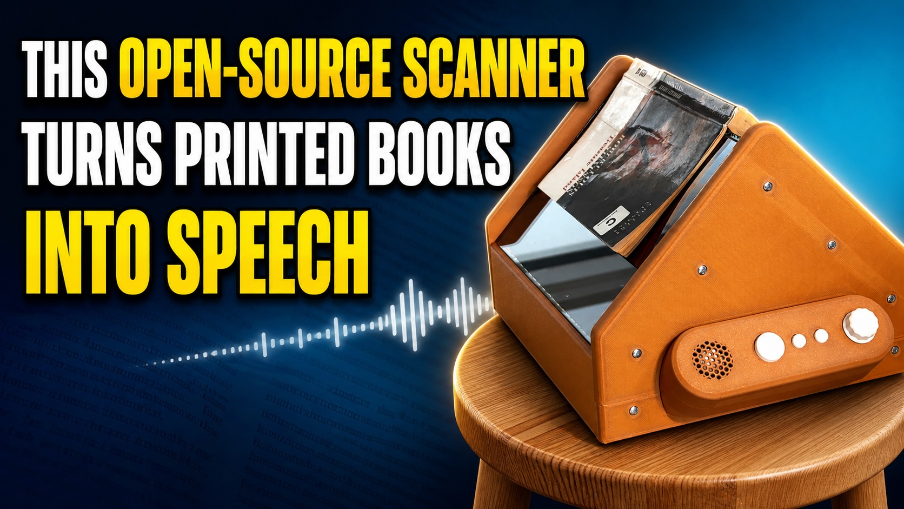
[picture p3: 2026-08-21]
images/thumbnail.jpg

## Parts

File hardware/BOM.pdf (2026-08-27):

# BOM Accessible Book Reader

Number | item | source | link
| 1 glas panel, 162 mm x 244 mm, thickness: 4 mm | eBay | https://ebay.io/m/Z96DEo
| 1 glas panel, 166 mm x 244 mm, thickness: 4 mm | eBay | https://ebay.io/m/Z96DEo
| 1 Raspberry Pi 5, 4GB RAM | generic | https://www.raspberrypi.com/products/raspberry-pi-5/
| 1 Raspberry Pi 5 active cooler | generic | https://www.raspberrypi.com/products/active-cooler/

2

| Arducam for Raspberry Pi camera 16MP IMX519 with
| 140°(D) wide angle-M12-lens | Amazon | https://amzn.eu/d/0j8CVnJm

1

| custom PCB RP extension board 'abr_pi5_header_v1'.
| Manufacturing data included in GitHub repository | JLCPCB

1

| custom PCB 'pn5180_adapter'. Manufacturing data
| included in GitHub repository | JLCPCB

1

| custom PCB 'pn5180_adapter_m'. Manufacturing data
| included in GitHub repository | JLCPCB

2

| custom PCB 'pn5180_relais'. Manufacturing data included
| in GitHub repository | JLCPCB

1

| custom PCB 'control_panel'. Manufacturing data included in
| GitHub repository | JLCPCB

1

| custom PCB 'rotary_switch'. Manufacturing data included in
| GitHub repository | JLCPCB

2

| assembled custom PCB 'LED_bar_long'. Manufacturing
| data included in GitHub repository | JLCPCB
| 2 pn5180 breakout board | eBay | https://ebay.io/m/mC5DxK
1-2m | 10-pin ribbon cable | generic | example: https://amzn.eu/d/0evFkoYO
| 6 female IDC connector 2x05 | generic | example: https://amzn.eu/d/0ixsqvHJ

## components for extension board:

| 1 pin header 2x20 pins | Amazon | https://amzn.eu/d/0gczZrjh
| 1 Raspberry Pi pico | generic | https://www.raspberrypi.com/products/raspberry-pi-pico/
| 3 IDC connector 2x05 pins | Amazon | https://amzn.eu/d/0bjwWq1a
| 2 JST XH connector male 1x02 | generic | example: https://amzn.eu/d/0al73FY1
| 2 power n-channel MOSFET, FQP30N06L | generic
| 1 470µF, 16V, electrolythic capacitor | generic
various | resistors | generic
| 1 MAX98357A breakout board | Amazon | https://amzn.eu/d/0iFmvlqy

## components for pn5180 adapter boards:

| 2 IDC connector 2x05 pins | Amazon | https://amzn.eu/d/0bjwWq1a

## components for pn5180 relais

| 1 CD4093 | generic
various | resistors | generic
various | capacitors | generic
| 2 Schottky diodes, 1N5819 | generic
| 1 n-channel MOSFET, 2N7000 | generic
| 1 relay, 5V, 2xum | Amazon | https://amzn.eu/d/03m9UJAE

## components for control panel

| 3 momentary switch | generic | example: https://ebay.io/m/XsXNOo

## components for rotary switch

| 1 rotary switch EC11 | generic | example: https://amzn.eu/d/046zOAI8
various | resistors | generic

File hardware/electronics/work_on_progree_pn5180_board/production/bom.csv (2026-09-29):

Designator | Footprint | Quantity | Value | LCSC Part #
C1 | 0603 | 1 | 1u | C15849
C10, C12, C13, C2, C3, C4, C5, C6 | 0402 | 8 | 100n | C1525
C11, C7, C8 | 0603 | 3 | 4u7 | C19666
C14, C15 | 0402 | 2 | 1nF | C1523
C16, C20 | 0402 | 2 | 15pF | C1548
C17, C18 | 0603 | 2 | 56pF | C39148
C19 | 0603 | 1 | 10uF | C96446
C21, C22, C35, C36 | 0603 | 4 | 68pF | C28262
C23, C38, C39 | C_aux | 3 | open
C24, C25, C27, C32 | C_aux | 4 | open
C28, C31 | 0603 | 2 | N.C.
C29, C30 | 0603 | 2 | 47pF | C1671
C33, C34 | 0603 | 2 | 100pF | C14858
C37 | 0603 | 1 | 1µF | C15849
C9 | 0603 | 1 | 470n | C1623
D1, D2 | D_SOD-323 | 2 | 1N5819WS | C191023
J1 | IDC-Header_2x05_P2.54mm_Vertical_centered | 1 | 10 pin IDC connector
JP2 | SolderJumper-2_P1.3mm_Open_RoundedPad1.0x1.5mm | 1 | Jumper_2_Open
L1, L2 | 0603 | 2 | 470nH | C341701
L4 | NFC_antenna | 1 | 1.33µH
Q1 | SOT-23 | 1 | AO3400A | C20917
R1 | 0402 | 1 | 10k | C25744
R10, R11 | 0603 | 2 | 2Ohm | C22977
R12, R15, R16, R9 | R_Axial_DIN0207_L6.3mm_D2.5mm_P10.16mm_Horizontal | 4 | open
R13, R8 | 0402 | 2 | 100k | C25741
R14, R17 | 0603 | 2 | 1Ohm | C22936
R2, R3 | 0402 | 2 | 0R | C17168
R4, R5 | 0402 | 2 | 4k7 | C25900
R6 | 0402 | 1 | 1k | C11702
R7 | 1206 | 1 | 0.1 | C25334
RL1 | Relay | 1 | JW2
U1 | 1pin | 1 | REQ
U10, U11, U12 | JLC_tooling_hole | 3 | ~
U13, U14, U6 | 1pin | 3 | GND
U2 | HVQFN-40-1EP_6x6mm_P0.5mm_EP4.1x4.1mm_ThermalVias | 1 | PN5180 | C1526287
U3 | 1pin | 1 | TX1
U4 | 1pin | 1 | TX2
U5 | 1pin | 1 | TX_supply
U7 | SOIC-14_3.9x8.7mm_P1.27mm | 1 | HEF4093B | C5456626
U8 | 1pin | 1 | 3.3V
U9 | 1pin | 1 | 5V
Y1 | Crystal_SMD_4Pin_A_3.2x2.5mm | 1 | 27.12 MHz | C29975

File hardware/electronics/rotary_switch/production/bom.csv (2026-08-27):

Designator | Footprint | Quantity | Value | LCSC Part #
J1 | 3_pin | 1 | Conn_01x03_Pin
J2 | 2_pin | 1 | Conn_01x02_Pin
SW1 | RotaryEncoder_Alps_EC11E-Switch_Vertical_H20mm | 1 | volume_knob

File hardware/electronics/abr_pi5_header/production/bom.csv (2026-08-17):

Designator | Footprint | Quantity | Value | LCSC Part #
A1 | RaspberryPiPico | 1 | SC0918
C1 | CP_Radial_D10.0mm_P5.00mm_slim_silkscreen | 1 | 470µ
J1 | 3_pin_jumper | 1 | Conn_01x03_Pin
J2 | RPI_HAT_back | 1 | RPi_GPIO
J3, J7 | JST_XH_B2B-XH-A_1x02_P2.50mm_Vertical | 2 | Conn_01x02_Pin
J4, J6 | JST_XH_B4B-XH-A_1x04_P2.50mm_Vertical | 2 | Conn_01x04_Pin
J5 | JST_XH_B7B-XH-A_1x07_P2.50mm_Vertical | 1 | Conn_01x07_Pin
J8 | 3_pin_jumper | 1 | ext. supply
Q1 | TO220_horizontal | 1 | FQP30N06L
R1 | R_Axial_DIN0207_L6.3mm_D2.5mm_P10.16mm_Horizontal | 1 | 100
R2 | R_Axial_DIN0207_L6.3mm_D2.5mm_P10.16mm_Horizontal | 1 | 100k
U1 | MAX98357A_breakout | 1 | MAX98357A

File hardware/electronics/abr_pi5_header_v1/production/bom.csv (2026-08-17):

Designator | Footprint | Quantity | Value | LCSC Part #
A1 | RaspberryPiPico | 1 | SC0918
C1 | CP_Radial_D10.0mm_P5.00mm_slim_silkscreen | 1 | 470µ
J1 | 3_pin_jumper | 1 | Conn_01x03_Pin
J2 | RPI_HAT_back | 1 | RPi_GPIO
J4, J5, J6 | IDC-Header_2x05_P2.54mm_Vertical_centered | 3 | 10 pin IDC connector
J7 | JST_XH_B2B-XH-A_1x02_P2.50mm_Vertical | 1 | LED_left
J8 | JST_XH_B2B-XH-A_1x02_P2.50mm_Vertical | 1 | LED_right
Q1, Q2 | TO220_vertikal | 2 | FQP30N06L
R1, R3 | R_Axial_DIN0207_L6.3mm_D2.5mm_P10.16mm_Horizontal | 2 | 100
R2, R4 | R_Axial_DIN0207_L6.3mm_D2.5mm_P10.16mm_Horizontal | 2 | 100k
U1 | MAX98357A_breakout | 1 | MAX98357A

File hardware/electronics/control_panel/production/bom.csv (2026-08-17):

Designator | Footprint | Quantity | Value | LCSC Part #
J1 | 3_pin | 1 | Conn_01x03_Pin
J2, J5 | 2_pin | 2 | Conn_01x02_Pin
J3 | IDC-Header_2x05_P2.54mm_Vertical_centered | 1 | 10 pin IDC connector
SW1, SW2, SW3 | OmronTaster | 3 | SW_MEC_5G

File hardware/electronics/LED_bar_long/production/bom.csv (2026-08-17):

Designator | Footprint | Quantity | Value | LCSC Part #
D1, D10, D11, D12, D13, D14, D15, D16, D17, D18, D19, D2, D20, D3, D4, D5, D6, D7, D8, D9 | LED_1206 | 20 | LED | C219234
J1, J2 | 2_pin | 2 | Conn_01x02_Pin
R1, R10, R11, R12, R13, R14, R15, R16, R17, R18, R19, R2, R20, R3, R4, R5, R6, R7, R8, R9 | 1206 | 20 | 100 | C17901
U1, U2, U3 | JLC_tooling_hole | 3 | ~

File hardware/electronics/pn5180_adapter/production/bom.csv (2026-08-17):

Designator | Footprint | Quantity | Value | LCSC Part #
J1 | 13_pin | 1 | Conn_01x13_Pin
J2 | IDC-Header_2x05_P2.54mm_Vertical_centered | 1 | 10 pin IDC connector

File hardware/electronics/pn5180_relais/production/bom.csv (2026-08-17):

Designator | Footprint | Quantity | Value | LCSC Part #
C1 | C_aux | 1 | 3pF | C1653
C2 | C_aux | 1 | 18pF | C1653
C3 | CP_Radial_D4.0mm_P1.50mm | 1 | 10µF
D1, D2 | D_A-405_P7.62mm_Horizontal | 2 | 1N5819 | C191023
J1 | 3_pin_hori | 1 | PN5180_in
J2 | 4_pin | 1 | Conn_01x04_Pin
L1 | NFC_antenna | 1 | 1.33µH
Q1 | TO-92_Inline | 1 | 2N7000
R1 | R_Axial_DIN0207_L6.3mm_D2.5mm_P10.16mm_Horizontal | 1 | 1k
R2, R3 | R_Axial_DIN0207_L6.3mm_D2.5mm_P10.16mm_Horizontal | 2 | 100k
RL1 | Relay | 1 | relay_mini
U1 | DIP-14_W7.62mm | 1 | HEF4093B | C5456626

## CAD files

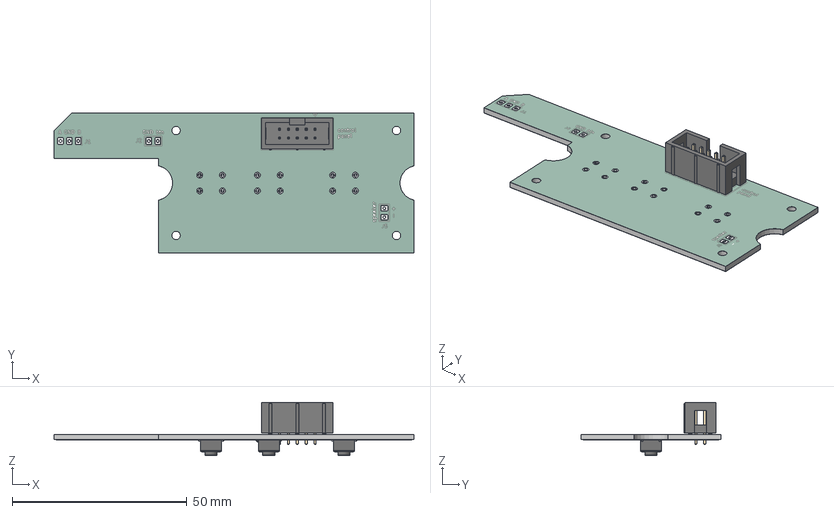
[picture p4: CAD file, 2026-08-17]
hardware/electronics/control_panel/control_panel.step
102.9 x 40.0 x 15.3 mm
IDC-Header_2x05_P2.54mm_Vertical
Omron_tactile_switch x 3
control_panel_copper
control_panel_pad
control_panel_via
control_panel_silkscreen
control_panel_soldermask
control_panel_PCB

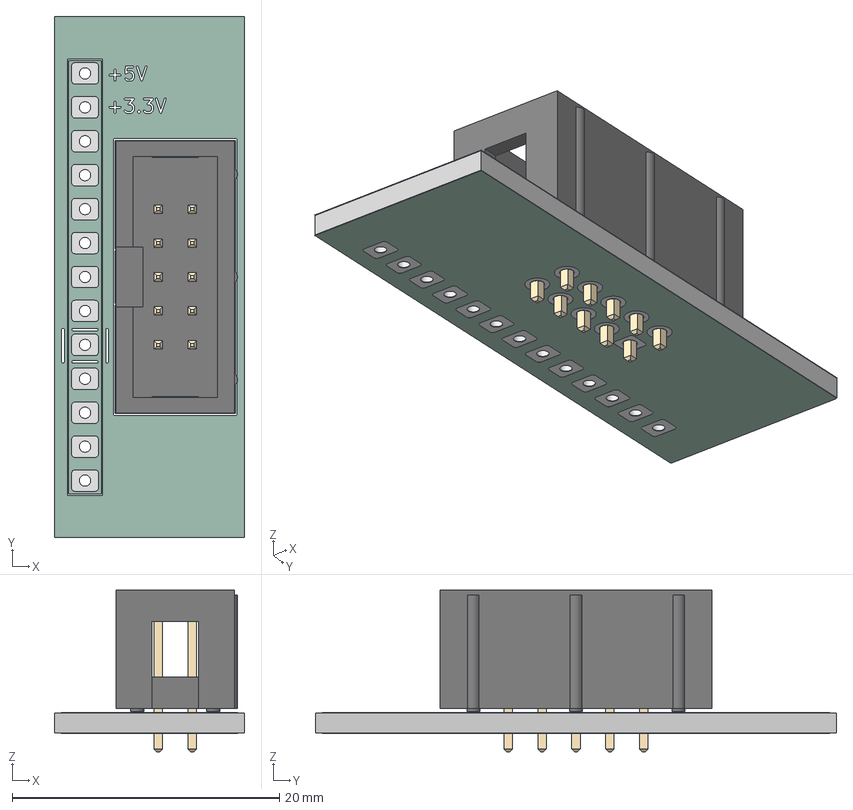
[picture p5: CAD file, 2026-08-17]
hardware/electronics/pn5180_adapter/pn5180_adapter.step
14.2 x 39.0 x 12.1 mm
IDC-Header_2x05_P2.54mm_Vertical
pn5180_adapter_copper
pn5180_adapter_pad
pn5180_adapter_silkscreen
pn5180_adapter_soldermask
pn5180_adapter_PCB

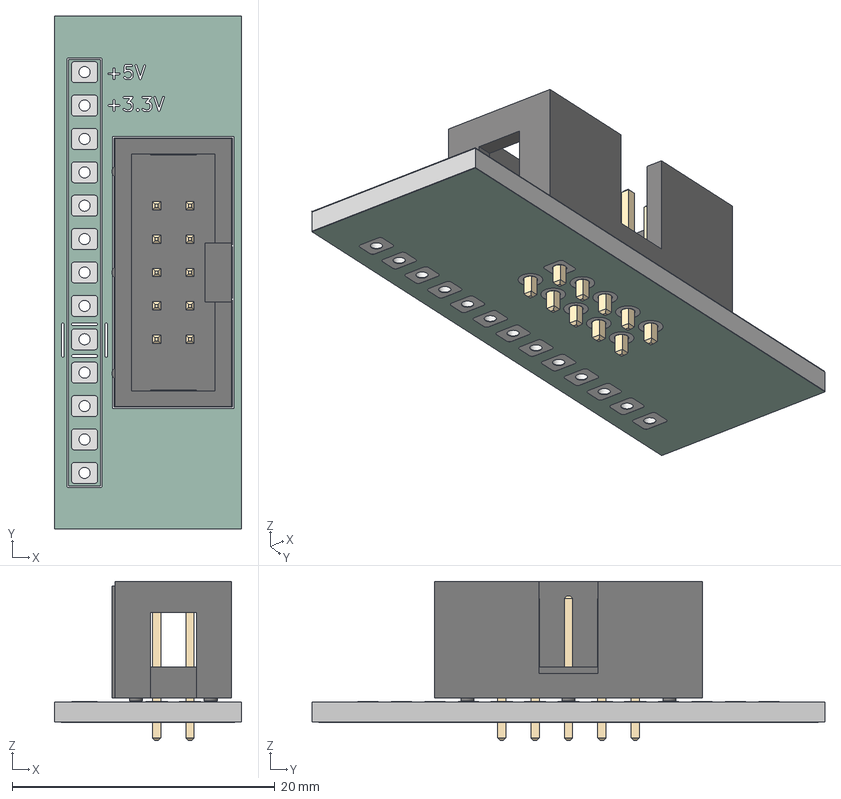
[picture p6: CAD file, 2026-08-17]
hardware/electronics/pn5180_adapter_m/pn5180_adapter_m.step
14.2 x 39.0 x 12.1 mm
IDC-Header_2x05_P2.54mm_Vertical
pn5180_adapter_m_copper
pn5180_adapter_m_pad
pn5180_adapter_m_via
pn5180_adapter_m_silkscreen
pn5180_adapter_m_soldermask
pn5180_adapter_m_PCB

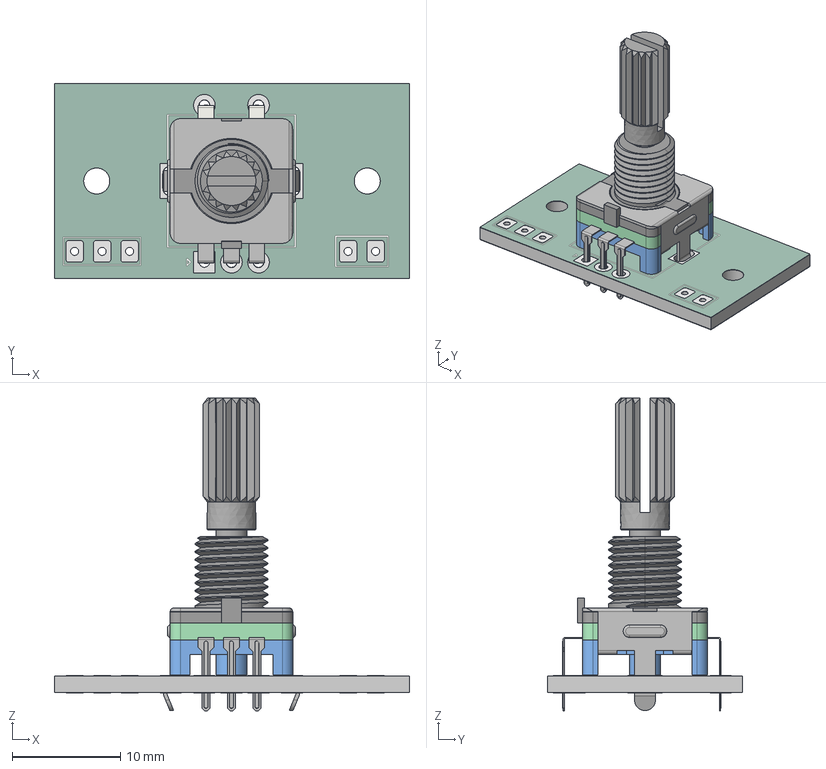
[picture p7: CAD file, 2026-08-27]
hardware/electronics/rotary_switch/rotary_switch.step
32.8 x 18.0 x 28.9 mm
EC11_Rotary_Encoder_Switched
rotary_switch_pad
rotary_switch_silkscreen
rotary_switch_soldermask
rotary_switch_PCB

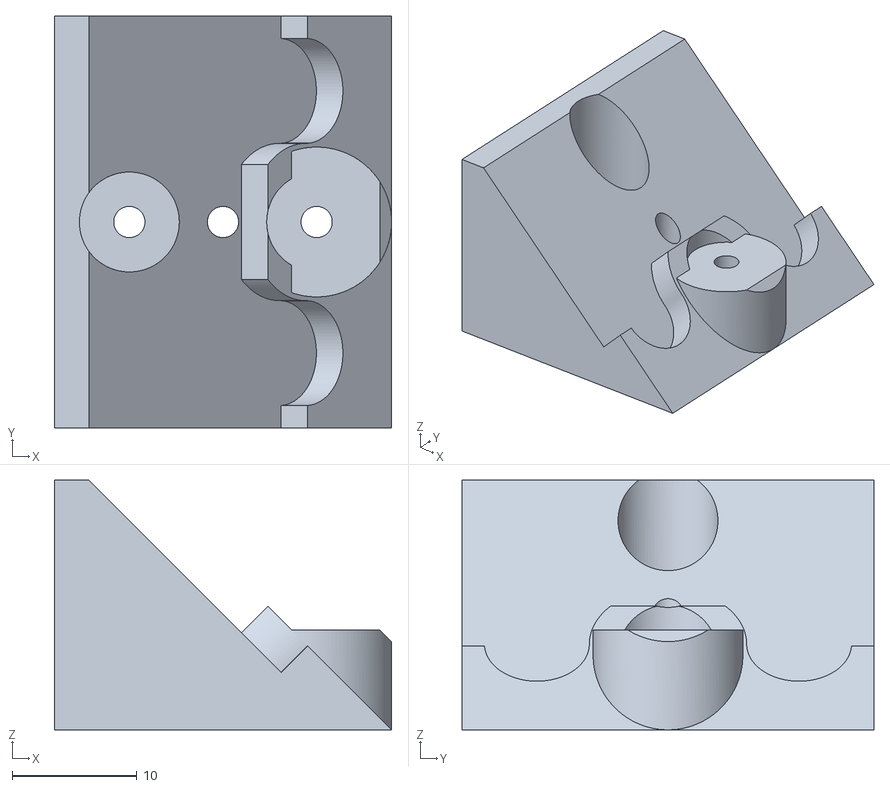
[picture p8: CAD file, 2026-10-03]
hardware/mechanics/camera_block_2_B.stl
27.0 x 33.0 x 20.0

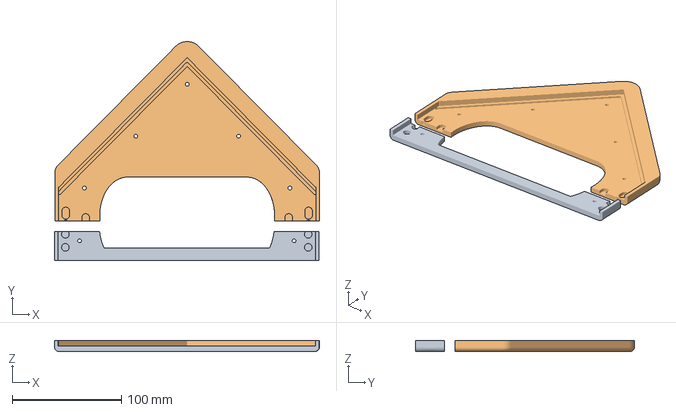
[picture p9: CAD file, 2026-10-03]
hardware/mechanics/front2_dev.3mf
243.1 x 200.8 x 10.0 mm
lower_front2_dev.stl
upper_front2_dev.stl

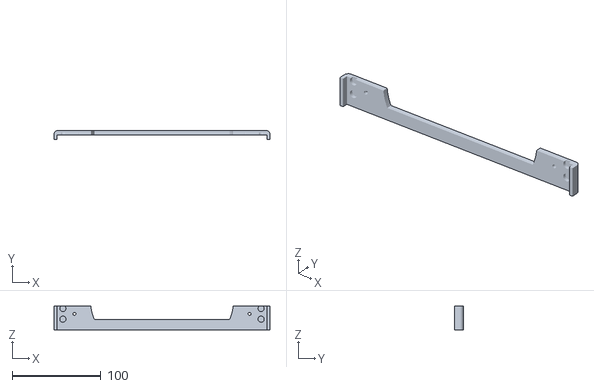
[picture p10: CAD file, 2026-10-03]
hardware/mechanics/lower_front2.stl
242.8 x 10.0 x 26.6

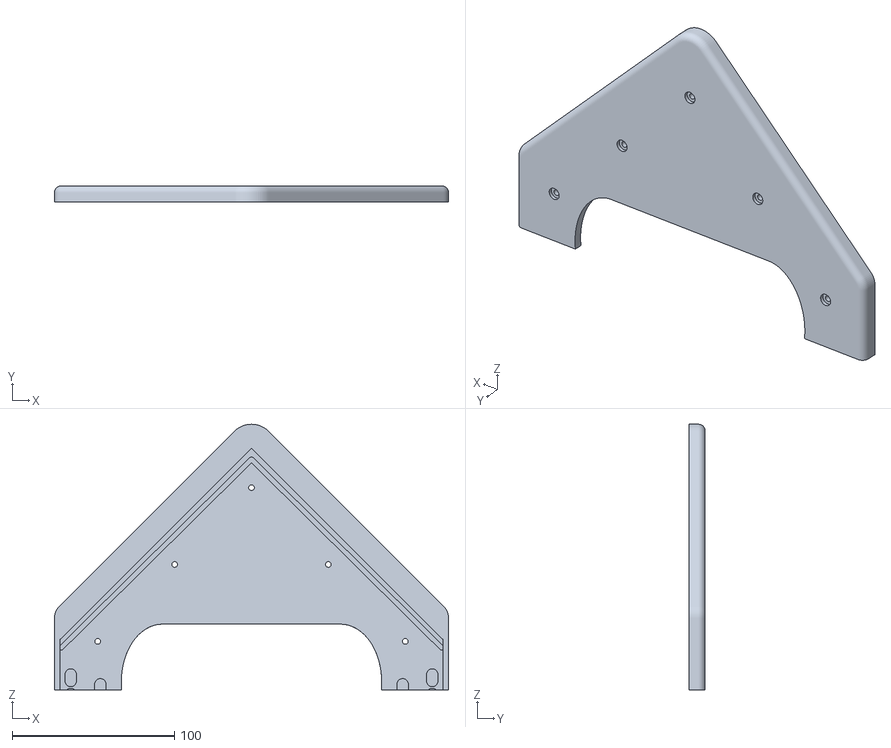
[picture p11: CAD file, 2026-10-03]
hardware/mechanics/upper_front2.stl
242.8 x 10.0 x 163.6

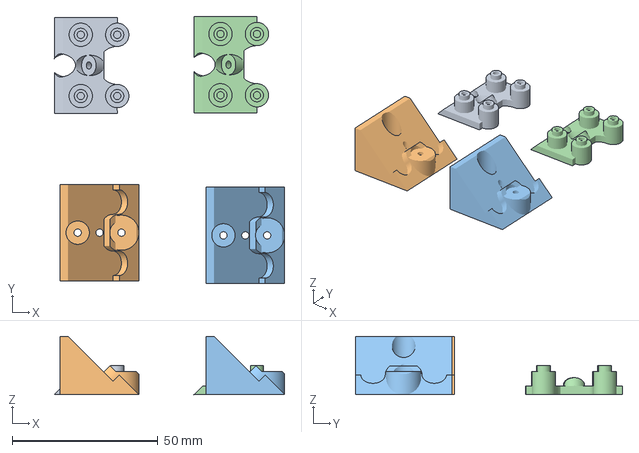
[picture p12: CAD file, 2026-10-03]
hardware/mechanics/camera_block_2.3mf
79.0 x 91.5 x 20.0 mm
camera_block_left_A.stl x 2
camera_block_left_B.stl x 2

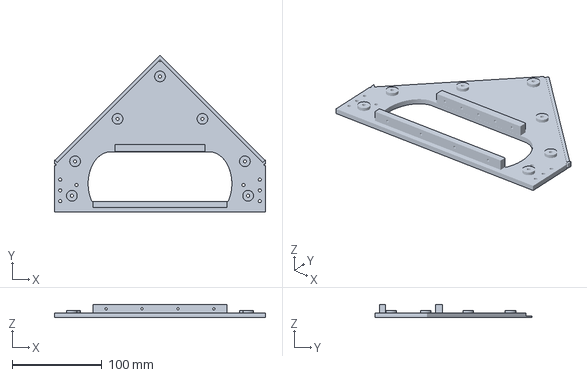
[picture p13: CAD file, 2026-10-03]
hardware/mechanics/front.3mf
235.5 x 174.9 x 15.0 mm

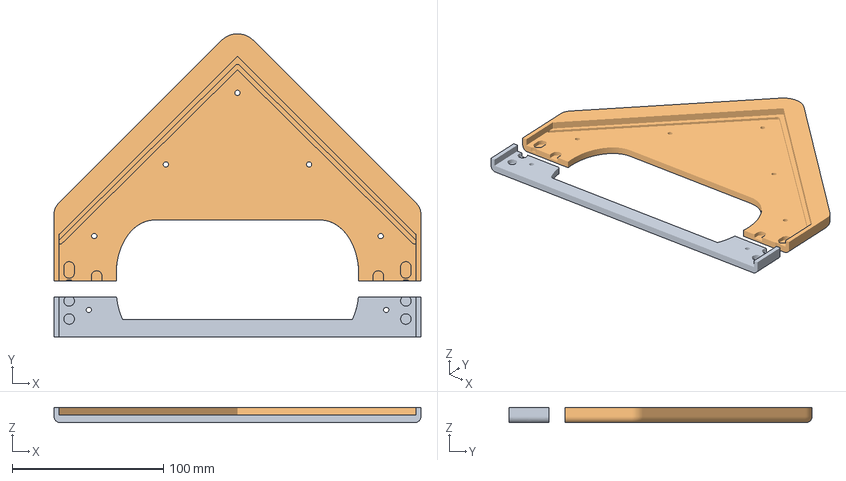
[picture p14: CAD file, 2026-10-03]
hardware/mechanics/front2.3mf
242.8 x 200.7 x 10.0 mm
lower_front2.stl
upper_front2.stl

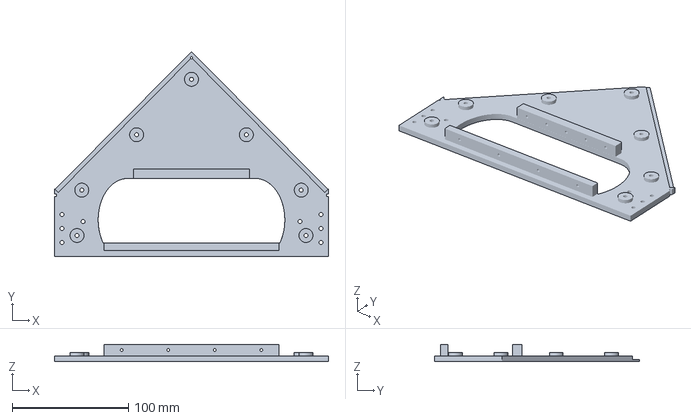
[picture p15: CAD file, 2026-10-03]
hardware/mechanics/front_dev.3mf
235.5 x 176.1 x 15.0 mm

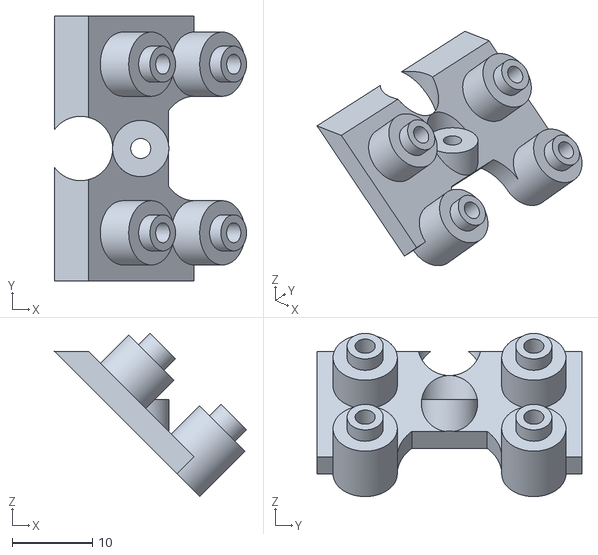
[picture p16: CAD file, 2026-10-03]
hardware/mechanics/camera_block_2_A.stl
23.9 x 33.0 x 20.3

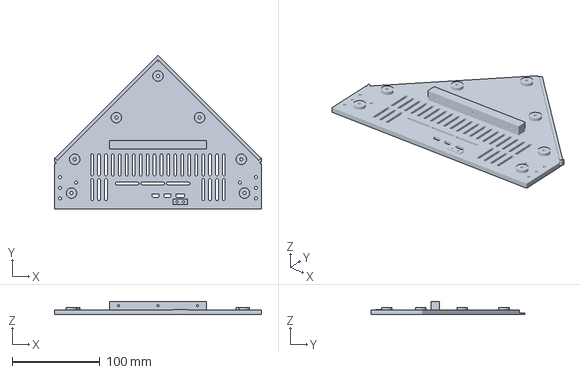
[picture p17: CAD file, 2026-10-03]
hardware/mechanics/back.3mf
235.5 x 174.9 x 15.0 mm

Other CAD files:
hardware/mechanics/upper_front2_dev.stl
hardware/mechanics/lower_front2_dev.stl
hardware/mechanics/side_right.3mf
hardware/mechanics/camera_block_left.stl
hardware/mechanics/LED_wedge.3mf
hardware/mechanics/LED_wedge_left.f3d
hardware/mechanics/LED_wedge_left.stl
hardware/mechanics/LED_wedge_right.f3d
hardware/mechanics/LED_wedge_right.stl
hardware/mechanics/PN5180_holder.3mf
hardware/mechanics/PN5180_holder.stl
hardware/mechanics/back.f3d
hardware/mechanics/back.stl
hardware/mechanics/back2.3mf
hardware/mechanics/back2.f3d
hardware/mechanics/back2.stl
hardware/mechanics/back2_dev.3mf
hardware/mechanics/back2_dev.f3d
hardware/mechanics/back2_dev.stl
hardware/mechanics/back_dev.3mf
hardware/mechanics/back_dev.f3d
hardware/mechanics/back_dev.stl
hardware/mechanics/bar.3mf
hardware/mechanics/bar.f3d
hardware/mechanics/bar.stl
hardware/mechanics/base_left.3mf
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

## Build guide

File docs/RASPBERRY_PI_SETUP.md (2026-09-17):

# Raspberry Pi Setup

Last reviewed: `2026-08-18`

Deutsche Fassung: [Raspberry-Pi-Setup](../docs_DE/RASPBERRY_PI_SETUP.md)

## Purpose and Target System

This guide describes a reproducible installation of the current ABR system on
a `Raspberry Pi 5`. It replaces the previous chronological setup log;
historical intermediate states and obsolete experiments have been removed.

Verified reference platform:

- 64-bit Debian/Raspberry Pi OS `Trixie` base
- Python `3.13`
- two `Arducam IMX519 16 MP` cameras
- Raspberry Pi Pico as the exclusive NFC gateway
- two PN5180 readers on the Pico; an alternative PN532 Pico path is available
- `MAX98357A` through I²S
- local OCR with RapidOCR
- Google Cloud TTS and Vertex AI/Gemini for summaries
- production runtime as `abr-control-panel.service`

Exact package versions may be newer. On a new installation, perform the
verification at the end of each major section.

## 1. Operating System and Network

`Raspberry Pi OS Lite (64-bit)` is recommended. When writing the SD card:

- set a hostname, for example `abr`
- enable SSH
- create a user account
- configure at least one Wi-Fi network or Ethernet initially

After the first boot:

```bash
ssh <pi-user>@abr.local
sudo apt update
sudo apt full-upgrade -y
sudo reboot
```

Reconnect and inspect the system:

```bash
cat /etc/os-release
uname -a
df -h
```

## 2. System Packages

```bash
sudo apt install -y \
  git curl ca-certificates \
  build-essential pkg-config \
  python3 python3-venv python3-pip python3-dev \
  tesseract-ocr tesseract-ocr-deu \
  libgl1 libopenblas-dev \
  espeak-ng alsa-utils pulseaudio-utils \
  python3-picamera2 \
  htop tmux
```

On Trixie, `libopenblas-dev` replaces the unavailable `libatlas-base-dev`.
The current camera test server does not require `python3-opencv`; OpenCV is
installed in the project virtual environment.

Verify:

```bash
python3 --version
git --version
tesseract --version
command -v aplay
command -v espeak-ng
```

## 3. Repository and Python Environment

```bash
mkdir -p ~/src
git clone https://github.com/lhm0/accessible_book_reader.git ~/src/abr
cd ~/src/abr
python3 -m venv .venv
source .venv/bin/activate
python -m pip install --upgrade pip
python -m pip install -e ".[ocr-rapidocr,dev,tts-google,nfc-pn532]"
```

Optional OCR backends:

```bash
python -m pip install -e ".[ocr-tesseract]"
python -m pip install -e ".[ocr-paddle]"
```

Never copy `.venv` from a Mac or another machine. If an incompatible
environment is present, move it aside and recreate it on the Pi:

```bash
cd ~/src/abr
mv .venv ".venv.incompatible.$(date +%Y%m%d-%H%M%S)"
python3 -m venv .venv
source .venv/bin/activate
python -m pip install --upgrade pip
python -m pip install -e ".[ocr-rapidocr,dev,tts-google,nfc-pn532]"
```

Verify the software:

```bash
python -c 'import abr, cv2, numpy; print("ABR import OK")'
python -m pytest -q
```

## 4. Boot Configuration for Cameras, UART, and I²S

The repository's `config.txt` is a reference only. Do not replace an existing
`/boot/firmware/config.txt` wholesale. Back it up first:

```bash
sudo cp /boot/firmware/config.txt /boot/firmware/config.txt.before-abr
sudo nano /boot/firmware/config.txt
```

The current hardware requires at least these entries in `[all]`:

```text
enable_uart=1
dtparam=i2s=on
dtoverlay=max98357a

camera_auto_detect=0
dtoverlay=imx519,cam0
dtoverlay=imx519,cam1
```

Also configure the header UART:

```bash
sudo raspi-config
```

Under `Interface Options -> Serial Port`:

- serial login shell: `No`
- serial hardware: `Yes`

Then reboot:

```bash
sudo reboot
```

## 5. Verify the Cameras

```bash
rpicam-hello --list-cameras
```

Two IMX519 cameras with indices `0` and `1` should be listed. Their maximum
sensor resolution is `4656x3496`.

The browser test server deliberately uses the system Python because Picamera2
is installed by the OS:

```bash
cd ~/src/abr
/usr/bin/python3 hardware/camera_test_server.py \
  --camera 0 --port 8000 --width 1920 --height 1080
```

Open `http://abr.local:8000/`. Test camera 1 on port 8001 in the same way. See
[CAMERA_TEST_SERVER.md](CAMERA_TEST_SERVER.md).

The included `calibration/out/cam0_planar.npz` and `cam1_planar.npz` remaps
apply only to the verified mechanical assembly. Regenerate them after changing
a camera, focus, angle, or height.

## 6. Pico NFC Gateway and UART

PN5180 and PN532 readers do not connect directly to the Pi. The Pi
communicates exclusively with the Raspberry Pi Pico over UART:

| Raspberry Pi 5 | Raspberry Pi Pico |
| --- | --- |
| `BCM14 / TXD`, pin 8 | `GP1 / RX` |
| `BCM15 / RXD`, pin 10 | `GP0 / TX` |
| `GND` | `GND` |

Use 3.3 V logic levels only. Complete wiring is documented in
[HARDWARE_GPIO_PLAN.md](HARDWARE_GPIO_PLAN.md). Gateway firmware:

- [PN5180 gateway](../hardware/pn5180_gateway/README.md), the current preferred
  dual-reader path
- [PN532 gateway](../hardware/pn532_gateway/README.md), alternative

ABR defaults to `/dev/ttyAMA0` at `115200 8N1`. Verify it with the shared
client or the compatibility wrapper:

```bash
cd ~/src/abr
source .venv/bin/activate
python hardware/pn5180_gateway_client.py --device /dev/ttyAMA0 PING
python hardware/pn5180_gateway_client.py --device /dev/ttyAMA0 STATUS
```

If access is denied, inspect the device and group membership:

```bash
ls -l /dev/ttyAMA0
groups
```

Changed group membership takes effect only after a new login or reboot.

## 7. MAX98357A and ALSA

Wiring:

```text
Raspberry Pi 5        MAX98357A
5V                    VIN
GND                   GND
BCM18                 BCLK
BCM19                 LRC / LRCLK / WS
BCM21                 DIN
BCM4 (optional)       SD / SD_MODE
SPK+ / SPK-           passive speaker
```

Use a passive `4 ohm / 3 W` or `8 ohm / 1–3 W` speaker. Never connect an
active speaker to `SPK+`/`SPK-`.

Because the runtime starts `aplay` without `-D`, `/etc/asound.conf` must use
the symbolic card name:

```text
pcm.!default {
    type plug
    slave.pcm "hw:CARD=MAX98357A,DEV=0"
}
```

The `plug` layer converts mono WAV files into the format expected by the
hardware path. Do not rely on changing numbers such as `card 2`.

Verify:

```bash
aplay -l
cat /proc/asound/cards
aplay -D default /usr/share/sounds/alsa/Front_Center.wav
```

Explicit comparison:

```bash
aplay -D plughw:CARD=MAX98357A,DEV=0 -vv \
  /usr/share/sounds/alsa/Front_Center.wav
```

For `Unknown error 524`, first check whether the explicit `plughw` command
works and whether `/etc/asound.conf` is correct. Kernel messages:

```bash
journalctl -k -b | grep -Ei 'snd|soc|asoc|i2s|max98357|pcm|dma'
```

## 8. Configure Google Cloud

The production runtime requires Application Default Credentials (`ADC`) for
Google Cloud Text-to-Speech and Vertex AI. Configure a Google Cloud project,
billing, and these APIs:

- `texttospeech.googleapis.com`
- `aiplatform.googleapis.com`

After installing the current Google Cloud CLI for Raspberry Pi OS:

```bash
gcloud services enable \
  texttospeech.googleapis.com \
  aiplatform.googleapis.com \
  --project YOUR_PROJECT_ID
gcloud auth application-default login
gcloud auth application-default set-quota-project YOUR_PROJECT_ID
gcloud config set project YOUR_PROJECT_ID
```

Credentials remain outside the repository in `~/.config/gcloud/`. Never copy
or commit them. A service account can alternatively be supplied through
Google's standard ADC mechanism.

Verify without printing secret tokens:

```bash
gcloud auth application-default print-access-token >/dev/null && echo "ADC OK"
gcloud config get-value project
```

The systemd installer sets `HOME` to the service user's home directory so the
same ADC store is available to the service.

## 9. Local Device Configuration and Language

```bash
cd ~/src/abr
sudo deploy/install_language_switch.sh
.venv/bin/python -m abr.language_config status
```

When missing, the installer creates `~/.config/abr/device.json` with mode
`0600` and German as the default. After installing the production service,
switch with:

```bash
sudo abr-language en
sudo abr-language de
abr-language status
```

The command restarts `abr-control-panel.service`; the selection applies to the
next scan and an active scan is terminated. Books are permanently bound to
the language active on their first scan. See
[LANGUAGE_PROFILES.md](LANGUAGE_PROFILES.md).

## 10. Install the Production Service

First stop any manually started runtime:

```bash
pgrep -af control_panel_service.py
```

Install and verify:

```bash
cd ~/src/abr
sudo deploy/install_control_panel_service.sh
sudo systemd-analyze verify /etc/systemd/system/abr-control-panel.service
systemctl status abr-control-panel.service --no-pager -l
```

The installer derives the user, group, home, repository, and `.venv` locally.
The unit starts the runtime at boot, sets `HOME` for ADC, uses the Pico UART
path, and restarts five seconds after an unexpected exit.

Operations and logs:

```bash
sudo systemctl restart abr-control-panel.service
sudo systemctl stop abr-control-panel.service
journalctl -u abr-control-panel.service -f
journalctl -u abr-control-panel.service -n 200 --no-pager
systemctl show abr-control-panel.service -p MainPID -p NRestarts
```

After a `git pull` containing code changes only:

```bash
cd ~/src/abr
sudo systemctl restart abr-control-panel.service
```

If dependencies or unit templates changed, update the virtual environment or
rerun the installer. See
[SYSTEMD_CONTROL_PANEL_SERVICE.md](SYSTEMD_CONTROL_PANEL_SERVICE.md) for
complete operating and diagnostic instructions.

## 11. Wi-Fi Profiles and Automatic Failover

Wi-Fi credentials remain exclusively in NetworkManager profiles. Add and
inspect profiles interactively:

```bash
cd ~/src/abr
source .venv/bin/activate
python -m abr.wifi_profiles list
python -m abr.wifi_profiles add
```

Configure persistent autoconnect for all stored profiles:

```bash
sudo deploy/install_wifi_autoconnect.sh
```

The installer creates a persistent root service,
`abr-wifi-autoconnect.service`, which cycles through saved Wi-Fi profiles
whenever disconnected, retrying indefinitely and preserving established
connections. Rerun the installer when updating an older installation.

See [WIFI_PROFILES.md](WIFI_PROFILES.md) for profile creation, safe switching,
and diagnostics.

## 12. Optional E-Mail Remote Maintenance

```bash
cd ~/src/abr
sudo deploy/install_remote_mail.sh
```

The first run creates `~/.config/abr/mail.ini` with mode `0600` and exits so
the file can be completed locally:

```ini
[mail]
address = abr-device@example.com
recipient = owner@example.com
username = abr-device@example.com
password = MAIL_APP_PASSWORD
smtp_host = smtp.example.com
smtp_port = 465
imap_host = imap.example.com
imap_port = 993
inbox = INBOX
```

Run the installer again afterward. Personal addresses and passwords remain
only in this untracked file.

```bash
sudo deploy/install_remote_mail.sh
systemctl status abr-email-upload.timer --no-pager
```

See [REMOTE_MAINTENANCE_EMAIL.md](REMOTE_MAINTENANCE_EMAIL.md) for complete
operating and security details.

## 13. Optional Usage Statistics

Install only after completing the mail configuration:

```bash
cd ~/src/abr
sudo deploy/install_usage_statistics.sh
systemctl status abr-usage-report.timer --no-pager
```

Statistics are stored below `library/`, use reporting periods from 04:00 to
04:00 in `Europe/Berlin`, and send reports through the local mail
configuration. See [USAGE_STATISTICS.md](USAGE_STATISTICS.md) for storage,
delivery, and diagnostic details.

## 14. Complete Verification

```bash
cd ~/src/abr
source .venv/bin/activate
python -m pytest -q
rpicam-hello --list-cameras
python hardware/pn5180_gateway_client.py --device /dev/ttyAMA0 STATUS
aplay -D default /usr/share/sounds/alsa/Front_Center.wav
abr-language status
systemctl is-active abr-control-panel.service
journalctl -u abr-control-panel.service -n 100 --no-pager
```

This checklist verifies the installation path itself. The final acceptance
test is normal operation through the front panel: identify a book, scan a
spread, hear both pages in order, stop playback, and invoke both summary
buttons while monitoring the service journal for errors.

## Local and Generated Configuration

| Path | Purpose | In repository? |
| --- | --- | --- |
| `/boot/firmware/config.txt` | cameras, UART, and I²S | No |
| `/etc/asound.conf` | ALSA default for MAX98357A | No |
| `~/.config/gcloud/` | Google ADC and project configuration | No |
| `~/.config/abr/device.json` | active book language | No |
| `~/.config/abr/mail.ini` | optional mail credentials | No |
| NetworkManager profiles | Wi-Fi credentials | No |
| `/etc/systemd/system/abr-*` | locally generated units and timers | No |
| `calibration/out/*_planar.npz` | mechanics-specific remaps | reference files included |

No `.env` file is required. Experimental backends read optional API keys only
from the local process environment. The production Google path uses ADC.

## Updating an Existing Installation

After the one-time history cleanup of the public repository, old local
branches may diverge from the new `origin/main`. Back up local changes before
a hard synchronization. If no local changes need to be retained:

```bash
cd ~/src/abr
git fetch origin
git reset --hard origin/main
```

For ordinary later updates:

```bash
cd ~/src/abr
git pull --ff-only
source .venv/bin/activate
python -m pip install -e ".[ocr-rapidocr,dev,tts-google,nfc-pn532]"
sudo deploy/install_language_switch.sh
sudo deploy/install_control_panel_service.sh
sudo systemctl restart abr-control-panel.service
```

Optional installers need to be rerun only if their templates or configuration
changed.

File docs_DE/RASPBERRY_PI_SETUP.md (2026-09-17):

# Raspberry-Pi-Setup

Stand: `2026-08-18`

English version: [Raspberry Pi Setup](../docs/RASPBERRY_PI_SETUP.md)

## Zweck und Zielsystem

Diese Anleitung beschreibt eine reproduzierbare Neuinstallation des aktuellen
ABR-Systems auf einem `Raspberry Pi 5`. Sie ersetzt das frühere chronologische
Einrichtungsprotokoll; historische Zwischenstände und bereits überholte
Versuchswege wurden entfernt.

Verifizierte Referenzplattform:

- Debian/Raspberry-Pi-OS-Basis `Trixie`, 64 Bit
- Python `3.13`
- zwei `Arducam IMX519 16 MP`
- Raspberry Pi Pico als ausschließliches NFC-Gateway
- zwei PN5180 am Pico; alternativer PN532-Pico-Pfad vorhanden
- `MAX98357A` über I²S
- lokale OCR mit RapidOCR
- Google Cloud TTS und Vertex AI/Gemini für Zusammenfassungen
- produktive Runtime als `abr-control-panel.service`

Die genauen Paketversionen dürfen neuer sein. Bei einer Neuinstallation soll
nach jedem Hauptabschnitt die angegebene Prüfung durchgeführt werden.

## 1. Betriebssystem und Netzwerk

Empfohlen wird `Raspberry Pi OS Lite (64-bit)`. Beim Schreiben der SD-Karte:

- Hostname, beispielsweise `abr`, setzen
- SSH aktivieren
- Benutzerkonto anlegen
- zunächst mindestens ein WLAN oder Ethernet konfigurieren

Nach dem ersten Boot:

```bash
ssh <pi-user>@abr.local
sudo apt update
sudo apt full-upgrade -y
sudo reboot
```

Nach dem Neustart erneut anmelden und den Stand prüfen:

```bash
cat /etc/os-release
uname -a
df -h
```

## 2. Systempakete

```bash
sudo apt install -y \
  git curl ca-certificates \
  build-essential pkg-config \
  python3 python3-venv python3-pip python3-dev \
  tesseract-ocr tesseract-ocr-deu \
  libgl1 libopenblas-dev \
  espeak-ng alsa-utils pulseaudio-utils \
  python3-picamera2 \
  htop tmux
```

`libopenblas-dev` ersetzt auf Trixie das nicht mehr verfügbare
`libatlas-base-dev`. `python3-opencv` ist für den aktuellen Kamera-Testserver
nicht erforderlich; OpenCV wird in der Projekt-venv installiert.

Prüfung:

```bash
python3 --version
git --version
tesseract --version
command -v aplay
command -v espeak-ng
```

## 3. Repository und Python-Umgebung

```bash
mkdir -p ~/src
git clone https://github.com/lhm0/accessible_book_reader.git ~/src/abr
cd ~/src/abr
python3 -m venv .venv
source .venv/bin/activate
python -m pip install --upgrade pip
python -m pip install -e ".[ocr-rapidocr,dev,tts-google,nfc-pn532]"
```

Optionale OCR-Backends:

```bash
python -m pip install -e ".[ocr-tesseract]"
python -m pip install -e ".[ocr-paddle]"
```

Die `.venv` darf nicht von einem Mac oder einem anderen Rechner kopiert
werden. Ist versehentlich eine fremde Umgebung vorhanden, diese zunächst
beiseitelegen und auf dem Pi neu erzeugen:

```bash
cd ~/src/abr
mv .venv ".venv.incompatible.$(date +%Y%m%d-%H%M%S)"
python3 -m venv .venv
source .venv/bin/activate
python -m pip install --upgrade pip
python -m pip install -e ".[ocr-rapidocr,dev,tts-google,nfc-pn532]"
```

Softwareprüfung:

```bash
python -c 'import abr, cv2, numpy; print("ABR import OK")'
python -m pytest -q
```

## 4. Boot-Konfiguration für Kamera, UART und I²S

Die Repository-Datei `config.txt` ist nur eine Referenz und darf eine
bestehende `/boot/firmware/config.txt` nicht vollständig ersetzen. Vor einer
Änderung eine Sicherung anlegen:

```bash
sudo cp /boot/firmware/config.txt /boot/firmware/config.txt.before-abr
sudo nano /boot/firmware/config.txt
```

Im Abschnitt `[all]` werden für den aktuellen Aufbau mindestens diese Einträge
benötigt:

```text
enable_uart=1
dtparam=i2s=on
dtoverlay=max98357a

camera_auto_detect=0
dtoverlay=imx519,cam0
dtoverlay=imx519,cam1
```

Für den Header-UART zusätzlich über `raspi-config` sicherstellen:

```bash
sudo raspi-config
```

Unter `Interface Options -> Serial Port`:

- Login-Shell über Serial: `No`
- Serial-Hardware: `Yes`

Danach neu starten:

```bash
sudo reboot
```

## 5. Kameras prüfen

```bash
rpicam-hello --list-cameras
```

Erwartet werden zwei IMX519 mit den Indizes `0` und `1`. Die maximale
Sensorauflösung ist `4656x3496`.

Der Browser-Testserver verwendet bewusst das System-Python, weil Picamera2
über das OS installiert ist:

```bash
cd ~/src/abr
/usr/bin/python3 hardware/camera_test_server.py \
  --camera 0 --port 8000 --width 1920 --height 1080
```

Im Browser `http://abr.local:8000/` öffnen. Kamera 1 kann analog auf Port 8001
getestet werden. Details:
[CAMERA_TEST_SERVER.md](CAMERA_TEST_SERVER.md).

Die mitgelieferten Remaps
`calibration/out/cam0_planar.npz` und `cam1_planar.npz` gelten nur für den
verifizierten mechanischen Aufbau. Nach Änderungen an Kamera, Fokus, Winkel
oder Höhe müssen sie neu erzeugt werden.

## 6. Pico-NFC-Gateway und UART

PN5180 und PN532 werden nicht direkt mit dem Pi verbunden. Der Pi kommuniziert
ausschließlich per UART mit dem Raspberry Pi Pico:

| Raspberry Pi 5 | Raspberry Pi Pico |
| --- | --- |
| `BCM14 / TXD`, Pin 8 | `GP1 / RX` |
| `BCM15 / RXD`, Pin 10 | `GP0 / TX` |
| `GND` | `GND` |

Nur 3,3-V-Pegel verwenden. Die vollständige Verdrahtung steht in
[HARDWARE_GPIO_PLAN.md](HARDWARE_GPIO_PLAN.md). Gateway-Firmware:

- [PN5180-Gateway](../hardware/pn5180_gateway/README.md), aktueller
  bevorzugter Zwei-Reader-Pfad
- [PN532-Gateway](../hardware/pn532_gateway/README.md), Alternative

Auf dem Pi verwendet ABR standardmäßig `/dev/ttyAMA0` mit `115200 8N1`.
Prüfung mit dem gemeinsamen Client beziehungsweise den Kompatibilitäts-
Wrappern:

```bash
cd ~/src/abr
source .venv/bin/activate
python hardware/pn5180_gateway_client.py --device /dev/ttyAMA0 PING
python hardware/pn5180_gateway_client.py --device /dev/ttyAMA0 STATUS
```

Falls `Permission denied` erscheint, Gruppen und Gerätezugriff prüfen:

```bash
ls -l /dev/ttyAMA0
groups
```

Eine geänderte Gruppenzugehörigkeit wird erst nach einer neuen Anmeldung oder
einem Neustart wirksam.

## 7. MAX98357A und ALSA

Verdrahtung:

```text
Raspberry Pi 5        MAX98357A
5V                    VIN
GND                   GND
BCM18                 BCLK
BCM19                 LRC / LRCLK / WS
BCM21                 DIN
BCM4 (optional)       SD / SD_MODE
SPK+ / SPK-           passiver Lautsprecher
```

Empfohlen ist ein passiver Lautsprecher mit `4 Ohm / 3 W` oder
`8 Ohm / 1–3 W`. Niemals einen Aktivlautsprecher an `SPK+`/`SPK-` anschließen.

Da `aplay` in der Runtime ohne `-D` gestartet wird, muss
`/etc/asound.conf` den symbolischen Kartennamen verwenden:

```text
pcm.!default {
    type plug
    slave.pcm "hw:CARD=MAX98357A,DEV=0"
}
```

Der `plug`-Layer konvertiert mono erzeugte WAV-Dateien in das vom
Hardwarepfad erwartete Format. Nicht auf wechselnde Nummern wie `card 2`
verlassen.

Prüfung:

```bash
aplay -l
cat /proc/asound/cards
aplay -D default /usr/share/sounds/alsa/Front_Center.wav
```

Expliziter Gegencheck:

```bash
aplay -D plughw:CARD=MAX98357A,DEV=0 -vv \
  /usr/share/sounds/alsa/Front_Center.wav
```

Bei `Unknown error 524` zuerst prüfen, ob der explizite `plughw`-Test
funktioniert und `/etc/asound.conf` korrekt ist. Kernelmeldungen:

```bash
journalctl -k -b | grep -Ei 'snd|soc|asoc|i2s|max98357|pcm|dma'
```

## 8. Google Cloud konfigurieren

Die produktive Runtime benötigt Application Default Credentials (`ADC`) für
Google Cloud Text-to-Speech und Vertex AI. Google-Cloud-Projekt, Abrechnung
und folgende APIs müssen eingerichtet sein:

- `texttospeech.googleapis.com`
- `aiplatform.googleapis.com`

Nach Installation der aktuellen Google Cloud CLI für Raspberry Pi OS:

```bash
gcloud services enable \
  texttospeech.googleapis.com \
  aiplatform.googleapis.com \
  --project YOUR_PROJECT_ID
gcloud auth application-default login
gcloud auth application-default set-quota-project YOUR_PROJECT_ID
gcloud config set project YOUR_PROJECT_ID
```

Die Anmeldedaten liegen außerhalb des Repositorys unter `~/.config/gcloud/`.
Sie dürfen niemals ins Projekt kopiert oder committet werden. Alternativ ist
ein Service Account über Googles regulären ADC-Mechanismus möglich.

Prüfung ohne Ausgabe geheimer Token:

```bash
gcloud auth application-default print-access-token >/dev/null && echo "ADC OK"
gcloud config get-value project
```

Der systemd-Installer setzt `HOME` auf das Home-Verzeichnis des
Dienstbenutzers, damit derselbe ADC-Speicher gefunden wird.

## 9. Lokale Gerätekonfiguration und Sprache

```bash
cd ~/src/abr
sudo deploy/install_language_switch.sh
.venv/bin/python -m abr.language_config status
```

Der Installer erzeugt bei Bedarf `~/.config/abr/device.json` mit Modus `0600`
und deutschem Default. Nach Installation des Produktionsdienstes kann mit den folgenden Befehlen
umgeschaltet werden:

```bash
sudo abr-language en
sudo abr-language de
abr-language status
```

Der Wechsel startet `abr-control-panel.service` neu und gilt ab dem nächsten
Scan. Ein laufender Scan wird dabei beendet. Bücher sind dauerhaft an die beim
ersten Scan aktive Sprache gebunden. Details:
[LANGUAGE_PROFILES.md](LANGUAGE_PROFILES.md).

## 10. Produktionsdienst installieren

Vorher eine eventuell manuell gestartete Runtime beenden:

```bash
pgrep -af control_panel_service.py
```

Dann installieren:

```bash
cd ~/src/abr
sudo deploy/install_control_panel_service.sh
sudo systemd-analyze verify /etc/systemd/system/abr-control-panel.service
systemctl status abr-control-panel.service --no-pager -l
```

Der Installer ermittelt Benutzer, Gruppe, Home, Repository und `.venv`
lokal. Die Unit startet die Runtime beim Boot, setzt `HOME` für ADC, verwendet
den Pico-UART-Pfad und startet nach unerwartetem Ende nach fünf Sekunden neu.

Betrieb und Log:

```bash
sudo systemctl restart abr-control-panel.service
sudo systemctl stop abr-control-panel.service
journalctl -u abr-control-panel.service -f
journalctl -u abr-control-panel.service -n 200 --no-pager
systemctl show abr-control-panel.service -p MainPID -p NRestarts
```

Nach einem `git pull` genügt bei reinen Codeänderungen:

```bash
cd ~/src/abr
sudo systemctl restart abr-control-panel.service
```

Wurden Abhängigkeiten oder Unit-Vorlagen geändert, stattdessen die venv
aktualisieren beziehungsweise den Installer erneut ausführen. Weitere Details
stehen derzeit in der deutschen
[SYSTEMD_CONTROL_PANEL_SERVICE.md](SYSTEMD_CONTROL_PANEL_SERVICE.md).

## 11. WLAN-Profile und automatisches Failover

WLAN-Zugangsdaten bleiben ausschließlich in NetworkManager-Profilen. Profile
interaktiv anlegen und prüfen:

```bash
cd ~/src/abr
source .venv/bin/activate
python -m abr.wifi_profiles list
python -m abr.wifi_profiles add
```

Autoconnect persistent für alle gespeicherten Profile konfigurieren:

```bash
sudo deploy/install_wifi_autoconnect.sh
```

Der Installer richtet `abr-wifi-autoconnect.service` als dauerhaften
Root-Dienst ein. Bei fehlender WLAN-Verbindung versucht er gespeicherte
Profile reihum und wiederholt die Suche unbegrenzt. Bestehende Verbindungen
bleiben erhalten. Den Installer auch bei einem Update erneut ausfuehren.

Details stehen derzeit in der deutschen
[WIFI_PROFILES.md](WIFI_PROFILES.md).

## 12. Optionale E-Mail-Fernwartung

```bash
cd ~/src/abr
sudo deploy/install_remote_mail.sh
```

Der erste Lauf erzeugt `~/.config/abr/mail.ini` mit Modus `0600` und beendet
sich, damit die Datei lokal ausgefüllt werden kann:

```ini
[mail]
address = abr-device@example.com
recipient = owner@example.com
username = abr-device@example.com
password = MAIL_APP_PASSWORD
smtp_host = smtp.example.com
smtp_port = 465
imap_host = imap.example.com
imap_port = 993
inbox = INBOX
```

Danach den Installer erneut starten. Persönliche Adressen und Passwörter
bleiben ausschließlich in dieser nicht versionierten Datei.

```bash
sudo deploy/install_remote_mail.sh
systemctl status abr-email-upload.timer --no-pager
```

Details stehen derzeit in der deutschen
[REMOTE_MAINTENANCE_EMAIL.md](REMOTE_MAINTENANCE_EMAIL.md).

## 13. Optionale Nutzungsstatistik

Erst nach vollständiger Mail-Konfiguration installieren:

```bash
cd ~/src/abr
sudo deploy/install_usage_statistics.sh
systemctl status abr-usage-report.timer --no-pager
```

Die Statistik liegt unterhalb von `library/`, verwendet Zeiträume von 04:00
bis 04:00 Uhr in `Europe/Berlin` und versendet Berichte über die lokale
Mail-Konfiguration. Details stehen derzeit in der deutschen
[USAGE_STATISTICS.md](USAGE_STATISTICS.md).

## 14. Vollständige Prüfung

```bash
cd ~/src/abr
source .venv/bin/activate
python -m pytest -q
rpicam-hello --list-cameras
python hardware/pn5180_gateway_client.py --device /dev/ttyAMA0 STATUS
aplay -D default /usr/share/sounds/alsa/Front_Center.wav
abr-language status
systemctl is-active abr-control-panel.service
journalctl -u abr-control-panel.service -n 100 --no-pager
```

Diese Prüfliste verifiziert den Installationspfad. Der abschließende
Abnahmetest erfolgt über das Bedienpanel: Buch erkennen, eine Doppelseite
scannen, beide Seiten in richtiger Reihenfolge hören, die Wiedergabe stoppen
und beide Zusammenfassungstasten auslösen. Dabei das Dienstjournal auf Fehler
beobachten.

## Lokale und generierte Konfigurationen

| Pfad | Zweck | Im Repository? |
| --- | --- | --- |
| `/boot/firmware/config.txt` | Kamera, UART und I²S | Nein |
| `/etc/asound.conf` | ALSA-Default für MAX98357A | Nein |
| `~/.config/gcloud/` | Google ADC und Projektkonfiguration | Nein |
| `~/.config/abr/device.json` | aktive Buchsprache | Nein |
| `~/.config/abr/mail.ini` | optionale Mail-Zugangsdaten | Nein |
| NetworkManager-Profile | WLAN-Zugangsdaten | Nein |
| `/etc/systemd/system/abr-*` | lokal erzeugte Units und Timer | Nein |
| `calibration/out/*_planar.npz` | mechanikspezifische Remaps | Referenzdateien enthalten |

Eine `.env`-Datei ist nicht erforderlich. Experimentelle Backends lesen
optionale API-Schlüssel nur aus der lokalen Prozessumgebung. Der produktive
Google-Pfad verwendet ADC.

## Aktualisieren einer bestehenden Installation

Nach der einmaligen Historienbereinigung des öffentlichen Repositorys können
alte lokale Branches vom neuen `origin/main` abweichen. Vor einem harten
Abgleich eigene lokale Änderungen sichern. Wenn keine lokalen Änderungen
erhalten werden müssen:

```bash
cd ~/src/abr
git fetch origin
git reset --hard origin/main
```

Für normale spätere Aktualisierungen:

```bash
cd ~/src/abr
git pull --ff-only
source .venv/bin/activate
python -m pip install -e ".[ocr-rapidocr,dev,tts-google,nfc-pn532]"
sudo deploy/install_language_switch.sh
sudo deploy/install_control_panel_service.sh
sudo systemctl restart abr-control-panel.service
```

Optionale Installer müssen nur erneut laufen, wenn ihre Vorlagen oder
Konfiguration geändert wurden.

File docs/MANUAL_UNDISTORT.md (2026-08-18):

# Manual Undistortion

Last reviewed: `2026-06-26`

Deutsche Fassung: [Manuelle Entzerrung](../docs_DE/MANUAL_UNDISTORT.md)

## Purpose

This tool undistorts a single image using camera parameters supplied manually.
In the current project, it serves only as a fallback and comparison tool; it
is no longer the preferred calibration path.

File:

- [calibration/manual_undistort.py](../calibration/manual_undistort.py)

## Role in the Current Project

The script is deliberately not a calibration tool.

It accepts:

- camera matrix `K`
- distortion coefficients
- model selection: `fisheye` or `standard`

and uses them to write an undistorted image file.

This allows you to vary values step by step on the Mac and compare their
effects directly.

The currently preferred project path for the Pi cameras is instead:

- generate a `ChArUco` board:
  [CHARUCO_BOARD.md](CHARUCO_BOARD.md)
- calculate a fixed remap from a calibration image:
  [PLANAR_CHARUCO_REMAP.md](PLANAR_CHARUCO_REMAP.md)

## Preparation on the Mac

From the repository:

```bash
cd ~/src/abr
source .venv/bin/activate
```

If `opencv-python` is not yet installed in the local virtual environment:

```bash
pip install opencv-python numpy
```

## Recommendation for the Lens

For a `140-degree` wide-angle lens, start with the `fisheye` model.

It uses:

- `fx`
- `fy`
- `cx`
- `cy`
- `k1,k2,k3,k4`

## Examples

### Fisheye Model

```bash
python calibration/manual_undistort.py \
  --input calibration/test_input.jpg \
  --output calibration/out/fisheye_try_01.jpg \
  --model fisheye \
  --fx 2200 \
  --fy 2200 \
  --cx 2328 \
  --cy 1748 \
  --dist "0.08,-0.03,0.005,-0.001" \
  --balance 0.2
```

### Standard Model

```bash
python calibration/manual_undistort.py \
  --input calibration/test_input.jpg \
  --output calibration/out/standard_try_01.jpg \
  --model standard \
  --fx 2200 \
  --fy 2200 \
  --cx 2328 \
  --cy 1748 \
  --dist "-0.25,0.12,0.0,0.0,-0.03" \
  --alpha 0.0
```

## Parameter Notes

### Camera Matrix

- `fx`, `fy`: effective focal lengths in pixels
- `cx`, `cy`: optical center in pixels

A pragmatic starting point for a `4656x3496` image is:

- `cx = 2328`
- `cy = 1748`

This initially assumes that the optical center is at the image center.

### Fisheye Model

- `dist` expects exactly `k1,k2,k3,k4`
- `balance = 0.0`
  - more cropping
  - usually straighter output
- `balance = 1.0`
  - wider field of view
  - potentially more unwanted edge areas

### Standard Model

- `dist` expects exactly `k1,k2,p1,p2,k3`
- `alpha = 0.0`
  - maximum crop to the usable region
- `alpha = 1.0`
  - more of the border retained, with potentially larger black areas

## Practical Workflow

1. Place a test image in `calibration/`.
2. Start with the `fisheye` model.
3. Initially set `cx` and `cy` to the image center.
4. First vary only `k1` and `k2` approximately.
5. Fine-tune `k3` and `k4` afterward.
6. Adjust `balance` to obtain a useful compromise between cropping and
   straight lines.

## Suggested Initial Experiments

For strong barrel distortion with the fisheye model, these values may serve
as approximate search ranges:

- `fx = 1800` to `2600`
- `fy = 1800` to `2600`
- `k1 = 0.02` to `0.20`
- `k2 = -0.20` to `0.05`
- `k3 = -0.05` to `0.05`
- `k4 = -0.02` to `0.02`

These are deliberately only search ranges, not calibration values.

## Optional Faster Comparisons

For quick visual comparison between variants:

```bash
python calibration/manual_undistort.py \
  --input calibration/test_input.jpg \
  --output calibration/out/preview.jpg \
  --model fisheye \
  --fx 2200 \
  --fy 2200 \
  --cx 2328 \
  --cy 1748 \
  --dist "0.08,-0.03,0.005,-0.001" \
  --balance 0.2 \
  --preview-width 1600
```

Only the output file is resized, making visual comparisons faster.

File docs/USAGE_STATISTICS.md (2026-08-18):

# Usage Statistics

Last reviewed: `2026-08-07`

Deutsche Fassung: [Nutzerstatistik](../docs_DE/USAGE_STATISTICS.md)

## Purpose and Reporting Period

The device runtime records usage per book. In the `Europe/Berlin` time zone,
a reporting day starts at `04:00` and ends immediately before `04:00` the
following day.

The following values are recorded for each book:

- number of successfully ingested pages
- actual playback duration of page and summary audio
- number of chapter/latest-pages summary requests
- number of story-so-far summary requests

System prompts and signal sounds such as `bing.wav` do not count as reading
time. During incremental processing, the same page artifact may be reported
more than once; `scan_id` and `page_id` ensure that it is counted only once
within a reporting period. A new scan of the same book page counts again.

## Storage and Failure Safety

The current state is stored in:

```text
library/usage_statistics/current.json
```

Access from audio and ingest threads, as well as from the reporting process,
is serialized with a thread lock and file lock. The JSON file is replaced
atomically. Statistics errors are logged but do not interrupt the device's
primary function.

At `04:00`, `abr-usage-report.timer` starts the one-shot
`abr-usage-report.service`. It sends every completed reporting period that has
not yet been delivered to the recipient configured in `mail.ini`. A period is
removed from `current.json` and stored under the following path only after a
successful SMTP delivery:

```text
library/usage_statistics/archive/YYYY-MM-DD.json
```

Since the `2026-08-07` version, a report is sent for every completed period,
even when the device was not used. Such a report contains
`Keine Nutzung erfasst.` and totals of zero. Empty periods also receive an
archive file after successful delivery, preventing the same zero-usage report
from being sent again by a second manual service run. After the device has
been off for several days, periods that have not yet been archived are caught
up in chronological order.

If delivery fails or the Pi is switched off at `04:00`, the data is retained.
With `Persistent=true`, systemd catches up on the missed run; a later run still
sends every outstanding completed period.

## Installation on the Raspberry Pi

Prerequisites:

- the project is located at `~/src/abr`
- the virtual environment `~/src/abr/.venv` exists
- the existing mail account is configured in `~/.config/abr/mail.ini`
- the current project version has been transferred to the Pi

Install:

```bash
cd ~/src/abr
timedatectl status
sudo deploy/install_usage_statistics.sh
```

`Time zone` must show `Europe/Berlin`. Otherwise, set it with:

```bash
sudo timedatectl set-timezone Europe/Berlin
```

The installer substitutes the current user and the repository, Python,
library, and mail-configuration paths into the unit, installs both systemd
files, and enables the timer immediately.

Then restart the control-panel service so the runtime uses the new counters:

```bash
sudo systemctl restart abr-control-panel.service
```

Inspect the timer:

```bash
systemctl status abr-usage-report.timer
systemctl list-timers abr-usage-report.timer
```

## Manual Test

As soon as usage data exists, a preview e-mail can be sent immediately. It
does not change or archive the current counters:

```bash
cd ~/src/abr
.venv/bin/python -m abr.usage_report \
  --library-root library \
  --config ~/.config/abr/mail.ini \
  --preview-current
```

A regular run sends completed periods, including periods without usage. The
systemd service can be started manually after the next reporting boundary:

```bash
sudo systemctl start abr-usage-report.service
journalctl -u abr-usage-report.service -n 100 --no-pager
```

Alternatively, run the same regular operation directly:

```bash
.venv/bin/python -m abr.usage_report \
  --library-root library \
  --config ~/.config/abr/mail.ini
```

Inspect the statistics file:

```bash
python -m json.tool library/usage_statistics/current.json
```

After a successful delivery, the journal reports the period identifier and
archive path. On an SMTP error, the service exits with a failure status and
the period remains available for the next attempt.

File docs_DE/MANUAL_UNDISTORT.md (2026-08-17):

# Manual Undistort

Stand: `2026-06-26`

## Zweck

Dieses Werkzeug entzerrt ein einzelnes Bild mit manuell uebergebenen Kameraparametern. Im aktuellen Projektstand ist es nur noch ein Fallback- und Vergleichswerkzeug, nicht mehr der bevorzugte Kalibrierpfad.

Datei:

- [calibration/manual_undistort.py](../calibration/manual_undistort.py)

## Rolle Im Aktuellen Projektstand

Das Skript ist bewusst kein Kalibrierwerkzeug.

Es nimmt stattdessen:

- Kameramatrix `K`
- Distortion-Koeffizienten
- Modellwahl `fisheye` oder `standard`

und schreibt daraus eine entzerrte Bilddatei.

Damit kannst du am Mac Werte schrittweise variieren und die Wirkung direkt vergleichen.

Bevorzugter aktueller Projektpfad fuer die Pi-Kameras ist stattdessen:

- `ChArUco`-Board erzeugen: [docs/CHARUCO_BOARD.md](../docs/CHARUCO_BOARD.md)
- feste Remap aus Kalibrierbild berechnen: [docs/PLANAR_CHARUCO_REMAP.md](../docs/PLANAR_CHARUCO_REMAP.md)

## Vorbereitung Am Mac

Im Repo:

```bash
cd ~/src/abr
source .venv/bin/activate
```

Falls `opencv-python` in der lokalen `venv` noch fehlt:

```bash
pip install opencv-python numpy
```

## Empfehlung Fuer Dein Objektiv

Fuer ein `140 Grad`-Weitwinkelobjektiv ist zuerst das `fisheye`-Modell sinnvoll.

Verwende dort:

- `fx`
- `fy`
- `cx`
- `cy`
- `k1,k2,k3,k4`

## Beispielaufrufe

### Fisheye-Modell

```bash
python calibration/manual_undistort.py \
  --input calibration/test_input.jpg \
  --output calibration/out/fisheye_try_01.jpg \
  --model fisheye \
  --fx 2200 \
  --fy 2200 \
  --cx 2328 \
  --cy 1748 \
  --dist "0.08,-0.03,0.005,-0.001" \
  --balance 0.2
```

### Standardmodell

```bash
python calibration/manual_undistort.py \
  --input calibration/test_input.jpg \
  --output calibration/out/standard_try_01.jpg \
  --model standard \
  --fx 2200 \
  --fy 2200 \
  --cx 2328 \
  --cy 1748 \
  --dist "-0.25,0.12,0.0,0.0,-0.03" \
  --alpha 0.0
```

## Parameterhinweise

### Kameramatrix

- `fx`, `fy`: effektive Brennweiten in Pixel
- `cx`, `cy`: optisches Zentrum in Pixel

Pragmatischer Startwert fuer eine `4656x3496`-Aufnahme:

- `cx = 2328`
- `cy = 1748`

also erst einmal Bildmitte annehmen.

### Fisheye

- `dist` erwartet genau `k1,k2,k3,k4`
- `balance = 0.0`
  - mehr Beschnitt
  - meist geradliniger
- `balance = 1.0`
  - mehr Sichtfeld
  - eher mehr Randreste

### Standardmodell

- `dist` erwartet genau `k1,k2,p1,p2,k3`
- `alpha = 0.0`
  - maximaler Beschnitt auf brauchbaren Bereich
- `alpha = 1.0`
  - mehr Rand, mehr schwarze Flaechen moeglich

## Praktischer Workflow

1. Ein Testbild nach `calibration/` legen
2. Mit `fisheye` starten
3. `cx` und `cy` zunaechst auf Bildmitte setzen
4. zuerst nur `k1` und `k2` grob variieren
5. danach `k3` und `k4` feinjustieren
6. `balance` so einstellen, dass du einen brauchbaren Kompromiss aus Randbeschnitt und Geradlinigkeit bekommst

## Vorschlag Fuer Erste Versuche

Fuer starke Tonnenverzeichnung mit Fisheye-Modell koennen diese Startwerte als reine Naeherung helfen:

- `fx = 1800` bis `2600`
- `fy = 1800` bis `2600`
- `k1 = 0.02` bis `0.20`
- `k2 = -0.20` bis `0.05`
- `k3 = -0.05` bis `0.05`
- `k4 = -0.02` bis `0.02`

Das sind bewusst nur Suchbereiche, keine Kalibrierwerte.

## Optional Fuer Schnellere Vergleiche

Wenn du nur schnell Varianten vergleichen willst:

```bash
python calibration/manual_undistort.py \
  --input calibration/test_input.jpg \
  --output calibration/out/preview.jpg \
  --model fisheye \
  --fx 2200 \
  --fy 2200 \
  --cx 2328 \
  --cy 1748 \
  --dist "0.08,-0.03,0.005,-0.001" \
  --balance 0.2 \
  --preview-width 1600
```

Dann wird nur die Ausgabedatei zum schnelleren visuellen Vergleich verkleinert.

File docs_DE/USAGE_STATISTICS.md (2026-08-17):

# Nutzerstatistik

Stand: `2026-08-07`

## Zweck und Zeitraum

Die Geraeteruntime erfasst die Nutzung buchweise. Ein Statistiktag beginnt in
der Zeitzone `Europe/Berlin` um `04:00` Uhr und endet am Folgetag unmittelbar
vor `04:00` Uhr.

Pro Buch werden erfasst:

- Anzahl erfolgreich ingestierter Seiten
- tatsaechliche Dauer der Wiedergabe von Seiten- und Zusammenfassungsaudio
- Anzahl Nutzungen der Kapitel-/Letzte-Seiten-Zusammenfassung
- Anzahl Nutzungen von `Was bisher geschah`

Systemhinweise und Signalklaenge wie `bing.wav` zaehlen nicht zur Vorlesezeit.
Ein wegen des inkrementellen Ablaufs mehrfach gemeldetes Seitenartefakt wird
ueber `scan_id` und `page_id` innerhalb derselben Statistikperiode nur einmal
gezaehlt. Ein neuer Scan derselben Buchseite zaehlt dagegen erneut.

## Speicherung und Ausfallsicherheit

Der laufende Zustand liegt unter:

```text
library/usage_statistics/current.json
```

Zugriffe aus Audio- und Ingest-Threads sowie aus dem Report-Prozess sind per
Thread-Lock und Dateisperre serialisiert. Die JSON-Datei wird atomar ersetzt.
Ein Fehler der Statistik wird geloggt, unterbricht aber nicht die eigentliche
Geraetefunktion.

Um `04:00` startet `abr-usage-report.timer` den einmaligen Dienst
`abr-usage-report.service`. Dieser sendet alle abgeschlossenen, noch nicht
versandten Perioden an den in `mail.ini` konfigurierten Empfaenger. Erst nach erfolgreichem SMTP-
Versand wird eine Periode aus `current.json` entfernt und abgelegt unter:

```text
library/usage_statistics/archive/YYYY-MM-DD.json
```

Seit dem Stand vom `2026-08-07` wird fuer jede abgeschlossene Periode ein
Bericht versendet, auch wenn das Geraet gar nicht benutzt wurde. Ein solcher
Bericht enthaelt `Keine Nutzung erfasst.` und Gesamtwerte von null. Auch leere
Perioden erhalten nach erfolgreichem Versand eine Archivdatei. Dadurch wird
derselbe Nullbericht bei einem manuellen zweiten Dienstlauf nicht erneut
verschickt. Nach einer mehrtaegigen Abschaltung werden noch nicht archivierte
Perioden der Reihe nach nachgeholt.

Schlaegt der Versand fehl oder ist der Pi um `04:00` ausgeschaltet, bleiben
die Daten erhalten. Durch `Persistent=true` holt systemd den Lauf nach; ein
spaeterer Lauf versendet weiterhin alle noch offenen abgeschlossenen
Perioden.

## Installation auf dem Raspberry Pi

Voraussetzungen:

- das Projekt liegt wie bisher unter `~/src/abr`
- die virtuelle Umgebung `~/src/abr/.venv` existiert
- der vorhandene Mail-Account ist in `~/.config/abr/mail.ini` eingerichtet
- die aktuelle Projektversion wurde auf den Pi uebertragen

Installation:

```bash
cd ~/src/abr
timedatectl status
sudo deploy/install_usage_statistics.sh
```

Bei `Time zone` muss `Europe/Berlin` stehen. Falls nicht:

```bash
sudo timedatectl set-timezone Europe/Berlin
```

Das Skript setzt den aktuellen Benutzer, Repo-, Python-, Bibliotheks- und
Mailkonfigurationspfad in die Unit ein, installiert beide systemd-Dateien und
aktiviert den Timer sofort.

Danach den Control-Panel-Dienst neu starten, damit die Runtime die neuen
Zaehler verwendet:

```bash
sudo systemctl restart abr-control-panel.service
```

Timer kontrollieren:

```bash
systemctl status abr-usage-report.timer
systemctl list-timers abr-usage-report.timer
```

## Manueller Test

Sobald erste Nutzungsdaten erfasst wurden, kann sofort eine Vorschau-Mail
gesendet werden. Sie veraendert oder archiviert die laufenden Zaehler nicht:

```bash
cd ~/src/abr
.venv/bin/python -m abr.usage_report \
  --library-root library \
  --config ~/.config/abr/mail.ini \
  --preview-current
```

Die regulaere Ausfuehrung versendet abgeschlossene Perioden einschliesslich
Perioden ohne Nutzung. Der systemd-Dienst kann nach dem naechsten
Periodenwechsel manuell gestartet werden:

```bash
sudo systemctl start abr-usage-report.service
journalctl -u abr-usage-report.service -n 100 --no-pager
```

Alternativ laesst sich derselbe regulaere Lauf direkt ausfuehren:

```bash
.venv/bin/python -m abr.usage_report \
  --library-root library \
  --config ~/.config/abr/mail.ini
```

Statistikdatei ansehen:

```bash
python -m json.tool library/usage_statistics/current.json
```

Bei einem erfolgreichen Versand erscheint im Journal die gesendete
Periodenkennung und der Archivpfad. Bei einem SMTP-Fehler endet der Dienst mit
Fehlerstatus; die Periode bleibt fuer den naechsten Versuch erhalten.

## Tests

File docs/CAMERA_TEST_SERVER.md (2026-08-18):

# Camera Test Server

Last reviewed: `2026-07-01`

Deutsche Fassung: [Kamera-Testserver](../docs_DE/CAMERA_TEST_SERVER.md)

## Purpose

This script starts a small HTTP server on the `Raspberry Pi 5` and provides
two functional modes:

- `live`: displays the live image from a connected camera in a browser
- `review`: displays two images, one below the other, on a shared page and
  uses radio buttons at the top to switch between four sources:
  - `raw images`
  - `rectified images`
  - `enhanced images`
  - `OCR overlay`

The former `capture-review`, `ocr-review`, and `ocr-words-review` modes now
start the same review page with different initial selections.

The currently verified target setup is:

- `2` cameras connected to the `Raspberry Pi 5`
- one test server per camera running on the Pi
- test pages viewed from a Mac over the network
- review of the most recent capture results through `captures/latest/`
- review of the most recent OCR overlays through an appropriate OCR debug
  directory, currently usually `runs/latest_rapidocr/debug/`

## File

- Script: [hardware/camera_test_server.py](../hardware/camera_test_server.py)

## Prerequisites on the Pi

- at least one camera physically connected to `CAM0` or `CAM1`
- `Picamera2` installed on the Pi
- the camera detected by the Pi

For `--mode review`, the requirements are different:

- no active camera is required
- no `Picamera2` dependency is required
- the default sources are:
  - `captures/latest/raw/` for `raw images`
  - `captures/latest/case/` for `rectified images`
  - `captures/latest/debug/page_1|page_2/02_enhanced.png` for `enhanced images`
  - `runs/latest/debug/page_1|page_2/06_ocr_overlay.png` or
    `runs/latest_rapidocr/debug/page_1|page_2/06_ocr_overlay.png` for
    `OCR overlay`

Important driver and overlay findings for the hardware currently in use:

- camera: `Arducam IMX519 16 MP`
- `camera_auto_detect=1` was not sufficient on the current Pi setup
- verified configuration in `/boot/firmware/config.txt`:

```text
camera_auto_detect=0
dtoverlay=imx519,cam0
dtoverlay=imx519,cam1
```

Useful quick check on the Pi:

```bash
rpicam-hello --list-cameras
```

If `Picamera2` is not yet available in the system Python installation:

```bash
sudo apt update
sudo apt install -y python3-picamera2
```

Important notes:

- On Raspberry Pi OS, `Picamera2` is often more reliably available through
  the system Python installation than through an isolated virtual environment.
- `picamera2` was not available in the project's `.venv`.
- The verified test path therefore deliberately uses the system Python:

```bash
/usr/bin/python3 hardware/camera_test_server.py ...
```

Current implementation details:

- The server uses `Picamera2` directly with `JpegEncoder` and `FileOutput`.
- It no longer re-encodes frames through `OpenCV`.
- Consequently, `python3-opencv` is no longer required by the current camera
  test server.

## Starting the Server on the Pi

### Live mode

Typical preview for `CAM0`:

```bash
cd ~/src/abr
/usr/bin/python3 hardware/camera_test_server.py --camera 0 --port 8000 --width 1920 --height 1080
```

Typical preview for `CAM1`:

```bash
cd ~/src/abr
/usr/bin/python3 hardware/camera_test_server.py --camera 1 --port 8001 --width 1920 --height 1080
```

By default, the server binds to `0.0.0.0`, making it available on all network
interfaces.

At startup, the script reports information including:

- camera model
- selected resolution
- a Bonjour URL such as `http://abr.local:8000/`

### Review mode

Combined review page:

```bash
cd ~/src/abr
/usr/bin/python3 hardware/camera_test_server.py --mode review --port 8010
```

With `raw images` selected initially:

```bash
/usr/bin/python3 hardware/camera_test_server.py --mode review --port 8010 --review-source raw
```

With `enhanced images` selected initially:

```bash
/usr/bin/python3 hardware/camera_test_server.py --mode review --port 8010 --review-source enhanced
```

Using a different capture session directory:

```bash
/usr/bin/python3 hardware/camera_test_server.py --mode review --port 8010 --capture-session-dir captures/latest
```

Using a different OCR debug directory, for example for the lightweight
RapidOCR wrapper:

```bash
/usr/bin/python3 hardware/camera_test_server.py --mode review --port 8010 --ocr-debug-dir runs/latest_rapidocr/debug
```

## Access from a Mac

Open the following addresses in a browser on the Mac:

```text
http://abr.local:8000/
http://abr.local:8001/
http://abr.local:8010/
```

Alternatively, replace `abr.local` with the Pi's IP address.

## Behavior

Default script behavior:

- uses camera index `0`
- selects the largest detected sensor resolution unless an explicit size is
  provided
- streams the image as `MJPEG`
- updates as quickly as the camera, JPEG encoding, and network permit

In `review` mode, the script:

- reads the current state below `captures/latest/` and the configured OCR
  debug directory for every status request
- always displays exactly two images, one below the other
- switches between four sources using radio buttons at the top:
  - `raw`
  - `rectified`
  - `enhanced`
  - `ocr-overlay`
- uses the undistorted camera images from `raw/` for `raw`
- uses the rectified `case/left.jpg` and `case/right.jpg` for `rectified`
- uses `02_enhanced.png`, generated by `capture_double_page` or
  `enhance_for_ocr.py`, for `enhanced`
- uses `06_ocr_overlay.png`, generated by `run_fallback_pipeline.py`, for
  `ocr-overlay`; it may originate from either `run_fallback_pipeline.py` or
  `hardware/run_rapidocr.py`
- refreshes the browser view automatically when a new capture or OCR run
  writes new overlays
- displays the concrete left and right file paths, as well as missing files,
  below the images for the selected source; this makes an `ocr-overlay` path
  problem directly visible in the browser

For the first live test:

- do not start at full resolution
- `1920x1080` is a good starting point for a responsive preview with the
  `IMX519`
- the Pi-reported full resolution of `4656x3496` works for an MJPEG live view
  but is considerably slower

Additional endpoints:

- `/snapshot.jpg`
- `/status.json`
- `/review-status.json`

For example, snapshots can be saved directly from the Mac:

```bash
curl http://abr.local:8000/snapshot.jpg -o calibration/shots/cam0_charuco_01.jpg
curl http://abr.local:8001/snapshot.jpg -o calibration/shots/cam1_charuco_01.jpg
```

For camera alignment, an optional crosshair can be overlaid at the center of
the browser image. Starting the server with `--crosshair` enables it initially;
it can then be toggled on the page using a checkbox.

## Optional Parameters

```bash
/usr/bin/python3 hardware/camera_test_server.py --camera 0 --port 8000 --width 2304 --height 1296
```

Important options:

- `--mode`: `live` or `review`
- the legacy names `capture-review`, `ocr-review`, and `ocr-words-review`
  remain available as aliases that start `review`
- `--camera`: camera index, for example `0`
- `--host`: bind address, default `0.0.0.0`
- `--port`: HTTP port, default `8000`
- `--width` and `--height`: explicit target resolution instead of full
  resolution
- `--crosshair`: initially display the crosshair in the browser image
- `--frame-timeout`: maximum time without a new JPEG frame, default `3.0`
- `--jpeg-quality`: JPEG quality, default `90`
- `--capture-session-dir`: capture source for `--mode review`, default
  `captures/latest`
- `--ocr-debug-dir`: OCR overlay source for `--mode review`, default
  `runs/latest/debug`; usually `runs/latest_rapidocr/debug` for the current
  standard Pi workflow
- `--review-source`: initial selection: `raw`, `rectified`, `enhanced`, or
  `ocr-overlay`
- `--ocr-stage`: obsolete compatibility option from the former `ocr-review`
  mode; ignored

Full sensor resolution with a crosshair:

```bash
/usr/bin/python3 hardware/camera_test_server.py --camera 0 --port 8000 --crosshair
/usr/bin/python3 hardware/camera_test_server.py --camera 1 --port 8001 --crosshair
```

The full resolution of the `IMX519` cameras currently in use is:

- `4656 x 3496`

## Intended Use

The test server is deliberately limited to diagnostics during hardware setup:

- check framing
- check sharpness
- test exposure and lighting
- assess focus and distortion
- capture individual `ChArUco` calibration snapshots
- compare the latest rectified capture results in the browser without
  downloading files separately
- compare per-page OCR preprocessing directly from the actual debug artifacts
  in the browser
- compare the backend-independent OCR text overlay from
  `06_ocr_overlay.png` for both pages directly in the browser

It is not part of the production OCR/TTS pipeline.

## Useful Basic Camera Checks

Before investigating a Python problem, check the basic camera stack directly:

```bash
rpicam-hello --list-cameras
rpicam-hello -t 15000 -n
```

Note for the `Raspberry Pi 5`:

- `rpicam-vid -o test.h264` is not a useful basic check for this project if
  only the H.264 codec path fails.
- For a camera-only check, `rpicam-hello -t 15000 -n` is more informative.

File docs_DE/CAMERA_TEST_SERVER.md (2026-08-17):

# Camera Test Server

Stand: `2026-07-01`

## Zweck

Dieses Skript startet auf dem `Raspberry Pi 5` einen kleinen HTTP-Server und
arbeitet jetzt in zwei funktionalen Modi:

- `live`: zeigt das Livebild einer angeschlossenen Kamera im Browser
- `review`: zeigt auf einer gemeinsamen Seite immer zwei Bilder untereinander
  an und schaltet oben per Radio-Buttons zwischen vier Quellen um:
  - `raw images`
  - `entzerrte Bilder`
  - `enhanced images`
  - `OCR overlay`

Die frueheren Modi `capture-review`, `ocr-review` und `ocr-words-review`
starten jetzt dieselbe Review-Seite nur mit unterschiedlicher Vorauswahl.

Der aktuell verifizierte Zielpfad fuer den Hardwareaufbau ist:

- `2` Kameras am `Raspberry Pi 5`
- Start eines Testservers pro Kamera auf dem Pi
- Anzeige der Testseiten vom Mac aus ueber das Netzwerk
- Review der letzten Capture-Ergebnisse ueber `captures/latest/`
- Review der letzten OCR-Overlays ueber ein passendes OCR-Debug-Verzeichnis,
  aktuell meist `runs/latest_rapidocr/debug/`

## Datei

- Skript: [hardware/camera_test_server.py](../hardware/camera_test_server.py)

## Vorbedingungen Auf Dem Pi

- mindestens eine Kamera physisch an `CAM0` oder `CAM1` angeschlossen
- `Picamera2` ist auf dem Pi installiert
- die Kamera wird vom Pi erkannt

Fuer `--mode review` gilt stattdessen:

- keine laufende Kamera erforderlich
- keine `Picamera2`-Abhaengigkeit erforderlich
- verwendet standardmaessig:
  - `captures/latest/raw/` fuer `raw images`
  - `captures/latest/case/` fuer `entzerrte Bilder`
  - `captures/latest/debug/page_1|page_2/02_enhanced.png` fuer `enhanced images`
  - `runs/latest/debug/page_1|page_2/06_ocr_overlay.png` oder
    `runs/latest_rapidocr/debug/page_1|page_2/06_ocr_overlay.png` fuer `OCR overlay`

Wichtiger Treiber-/Overlay-Befund fuer die aktuell verwendete Hardware:

- Kamera: `Arducam IMX519 16 MP`
- auf dem aktuellen Pi-Setup war `camera_auto_detect=1` nicht ausreichend
- verifizierte Konfiguration in `/boot/firmware/config.txt`:

```text
camera_auto_detect=0
dtoverlay=imx519,cam0
dtoverlay=imx519,cam1
```

Sinnvolle Kurzpruefung auf dem Pi:

```bash
rpicam-hello --list-cameras
```

Wenn `Picamera2` im System-Python noch fehlt:

```bash
sudo apt update
sudo apt install -y python3-picamera2
```

Wichtig:

- auf Raspberry Pi OS ist `Picamera2` oft ueber das System-Python sauberer verfuegbar als in einer isolierten `venv`
- in der Projekt-`venv` war `picamera2` nicht verfuegbar
- der verifizierte Testpfad ist deshalb bewusst das System-Python:

```bash
/usr/bin/python3 hardware/camera_test_server.py ...
```

Aktueller Implementierungsstand des Testservers:

- der Server nutzt direkt `Picamera2` mit `JpegEncoder` und `FileOutput`
- er re-encodiert die Frames nicht mehr ueber `OpenCV`
- `python3-opencv` ist fuer den aktuellen Kamera-Testserver deshalb nicht mehr erforderlich

## Start Auf Dem Pi

### Live-Modus

Typische Vorschau fuer `CAM0`:

```bash
cd ~/src/abr
/usr/bin/python3 hardware/camera_test_server.py --camera 0 --port 8000 --width 1920 --height 1080
```

Typische Vorschau fuer `CAM1`:

```bash
cd ~/src/abr
/usr/bin/python3 hardware/camera_test_server.py --camera 1 --port 8001 --width 1920 --height 1080
```

Der Server bindet standardmaessig auf `0.0.0.0`, also auf allen Netzwerkschnittstellen.

Beim Start gibt das Skript unter anderem aus:

- Kameramodell
- verwendete Aufloesung
- Bonjour-Link wie `http://abr.local:8000/`

### Review-Modus

Gemeinsame Review-Seite:

```bash
cd ~/src/abr
/usr/bin/python3 hardware/camera_test_server.py --mode review --port 8010
```

Mit initialer Vorauswahl `raw images`:

```bash
/usr/bin/python3 hardware/camera_test_server.py --mode review --port 8010 --review-source raw
```

Mit initialer Vorauswahl `enhanced images`:

```bash
/usr/bin/python3 hardware/camera_test_server.py --mode review --port 8010 --review-source enhanced
```

Abweichendes Capture-Session-Verzeichnis:

```bash
/usr/bin/python3 hardware/camera_test_server.py --mode review --port 8010 --capture-session-dir captures/latest
```

Abweichendes OCR-Debug-Verzeichnis, z. B. fuer den schlanken RapidOCR-Wrapper:

```bash
/usr/bin/python3 hardware/camera_test_server.py --mode review --port 8010 --ocr-debug-dir runs/latest_rapidocr/debug
```

## Zugriff Vom Mac

Im Browser auf dem Mac oeffnen:

```text
http://abr.local:8000/
http://abr.local:8001/
http://abr.local:8010/
```

Alternativ statt `abr.local` die IP-Adresse des Pi verwenden.

## Verhalten

Standardverhalten des Skripts:

- verwendet Kameraindex `0`
- waehlt ohne Zusatzparameter die groesste gefundene Sensoraufloesung
- streamt das Bild als `MJPEG`
- aktualisiert so schnell, wie Kamera, JPEG-Encoding und Netzwerk es hergeben

Im `review`-Modus:

- liest das Skript bei jeder Statusabfrage den aktuellen Stand unter
  `captures/latest/` und dem jeweils konfigurierten OCR-Debug-Verzeichnis
- zeigt immer genau zwei Bilder untereinander an
- schaltet oben per Radio-Buttons zwischen vier Quellen um:
  - `raw`
  - `rectified`
  - `enhanced`
  - `ocr-overlay`
- verwendet fuer `raw` die unverzerrten Kamerabilder aus `raw/`
- verwendet fuer `rectified` die entzerrten `case/left.jpg` und `right.jpg`
- verwendet fuer `enhanced` die von `capture_double_page` oder
  `enhance_for_ocr.py` erzeugten `02_enhanced.png`
- verwendet fuer `ocr-overlay` die von `run_fallback_pipeline.py` erzeugten
  `06_ocr_overlay.png`; das kann aus `run_fallback_pipeline.py` oder aus
  `hardware/run_rapidocr.py` stammen
- aktualisiert die Browseransicht automatisch, sobald eine neue Aufnahme
  oder ein neuer OCR-Lauf neue Overlays geschrieben hat
- zeigt unterhalb der Bilder fuer die aktuell gewaehlte Quelle auch die
  konkreten linken/rechten Dateipfade und fehlende Dateien an; damit laesst
  sich ein Pfadproblem bei `ocr-overlay` direkt im Browser erkennen

Praktische Empfehlung fuer den ersten Live-Test:

- nicht sofort Vollaufloesung verwenden
- fuer die `IMX519` ist `1920x1080` ein guter Startpunkt fuer fluessige Vorschau
- die vom Pi gemeldete Vollaufloesung `4656x3496` ist fuer MJPEG-Livebild moeglich, aber deutlich langsamer

Zusaetzliche Endpunkte:

- `/snapshot.jpg`
- `/status.json`
- `/review-status.json`

Ein Snapshot laesst sich damit direkt vom Mac abspeichern, z. B.:

```bash
curl http://abr.local:8000/snapshot.jpg -o calibration/shots/cam0_charuco_01.jpg
curl http://abr.local:8001/snapshot.jpg -o calibration/shots/cam1_charuco_01.jpg
```

Fuer die Kamera-Justage kann das Browserbild optional mit einem Fadenkreuz in der Bildmitte ueberlagert werden.
Der Server-Start mit `--crosshair` blendet es initial ein; auf der Seite selbst laesst es sich dann per Checkbox ein- und ausblenden.

## Optionale Parameter

```bash
/usr/bin/python3 hardware/camera_test_server.py --camera 0 --port 8000 --width 2304 --height 1296
```

Wichtige Optionen:

- `--mode`: `live` oder `review`
- die alten Namen `capture-review`, `ocr-review` und `ocr-words-review`
  bleiben als Start-Aliasse fuer `review` erhalten
- `--camera`: Kameraindex, z. B. `0`
- `--host`: Bind-Adresse, Standard `0.0.0.0`
- `--port`: HTTP-Port, Standard `8000`
- `--width` und `--height`: explizite Zielaufloesung statt Vollaufloesung
- `--crosshair`: Fadenkreuz im Browserbild initial einblenden
- `--frame-timeout`: maximale Zeit ohne neues JPEG-Frame, Standard `3.0`
- `--jpeg-quality`: JPEG-Qualitaet, Standard `90`
- `--capture-session-dir`: Capture-Quelle fuer `--mode review`, Standard `captures/latest`
- `--ocr-debug-dir`: OCR-Overlay-Quelle fuer `--mode review`, Standard `runs/latest/debug`;
  fuer den aktuellen Pi-Standardlauf meist `runs/latest_rapidocr/debug`
- `--review-source`: initiale Auswahl `raw`, `rectified`, `enhanced` oder `ocr-overlay`
- `--ocr-stage`: veraltete Restoption aus dem frueheren `ocr-review`-Modus; wird ignoriert

Volle Sensoraufloesung mit Fadenkreuz:

```bash
/usr/bin/python3 hardware/camera_test_server.py --camera 0 --port 8000 --crosshair
/usr/bin/python3 hardware/camera_test_server.py --camera 1 --port 8001 --crosshair
```

Die Vollaufloesung der aktuell verwendeten `IMX519` liegt bei:

- `4656 x 3496`

## Erwartete Nutzung

Der Testserver ist bewusst nur ein Diagnosewerkzeug fuer den Hardwareaufbau:

- Bildausschnitt pruefen
- Schaerfe pruefen
- Belichtung und Licht testen
- Fokus und Verzeichnung beurteilen
- `ChArUco`-Kalibrierbilder als Einzel-Snapshot aufnehmen
- letzte entzerrte Capture-Ergebnisse ohne separaten Datei-Download im Browser vergleichen
- die OCR-Vorverarbeitung je Seite direkt auf den echten Debug-Artefakten im Browser vergleichen
- das backend-unabhaengige OCR-Text-Overlay aus `06_ocr_overlay.png` fuer beide Seiten direkt im Browser vergleichen

Er ist kein Bestandteil der spaeteren produktiven OCR-/TTS-Pipeline.

## Hilfreiche Kamera-Basischecks

Bevor ein Python-Problem gesucht wird, zuerst den nackten Kamera-Stack pruefen:

```bash
rpicam-hello --list-cameras
rpicam-hello -t 15000 -n
```

Hinweis fuer den `Raspberry Pi 5`:

- `rpicam-vid -o test.h264` ist kein guter Basischeck fuer dieses Projekt, wenn nur der H.264-Codec-Pfad scheitert
- fuer die reine Kamerapruefung ist `rpicam-hello -t 15000 -n` aussagekraeftiger

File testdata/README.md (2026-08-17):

# Testdata

Dieser Ordner enthaelt im Repository absichtlich keine realen Buchseiten.
Lokale Testbilder werden durch `.gitignore` ausgeschlossen, weil Bilder und
OCR-Inhalte aktueller Buecher in der Regel urheberrechtlich geschuetzt sind.
Nur selbst erstellte, gemeinfreie oder fuer eine Veroeffentlichung eindeutig
freigegebene Testvorlagen duerfen ausnahmsweise versioniert werden.

Lege hier reale Testfaelle ab. Empfohlene Struktur:

```text
testdata/
  roman_001/
    left.jpg
    right.jpg
```

Alternativ funktionieren auch die ersten beiden Bilddateien im Ordner. Die Namen `left.*` und `right.*` sind aber fuer reproduzierbare Tests empfohlen.

Fuer reale Scannerbilder ist eine getrennte Ablage pro Kamera sinnvoll, z. B.:

```text
testdata/
  scans0/
    cam0_0001.jpg
    cam0_0001_rectified.jpg
  scans1/
    cam1_0001.jpg
    cam1_0001_rectified.jpg
```

Empfohlene Konvention:

- rohe Aufnahme: `cam0_0001.jpg`, `cam1_0001.jpg`
- mit gespeicherter Remap entzerrt: `cam0_0001_rectified.jpg`, `cam1_0001_rectified.jpg`

Die aktuell dokumentierten Remaps liegen unter:

- `calibration/out/cam0_planar.npz`
- `calibration/out/cam1_planar.npz`

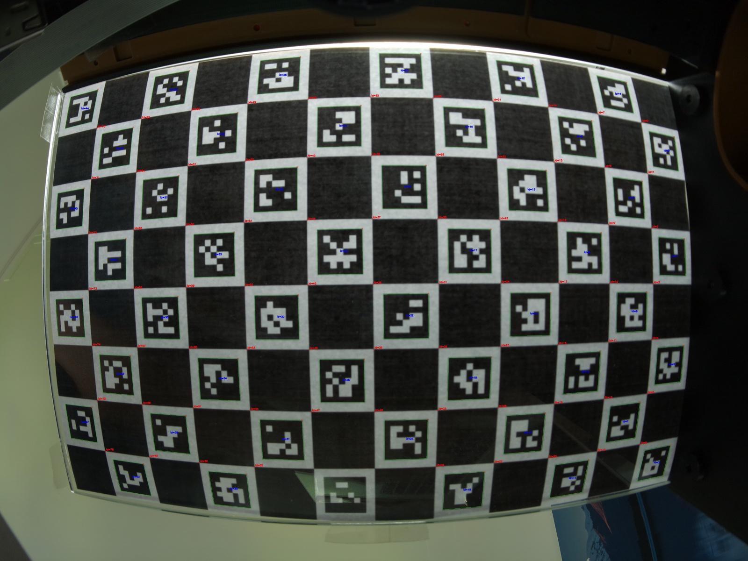
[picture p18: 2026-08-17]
calibration/out/cam1_planar_detected.jpg

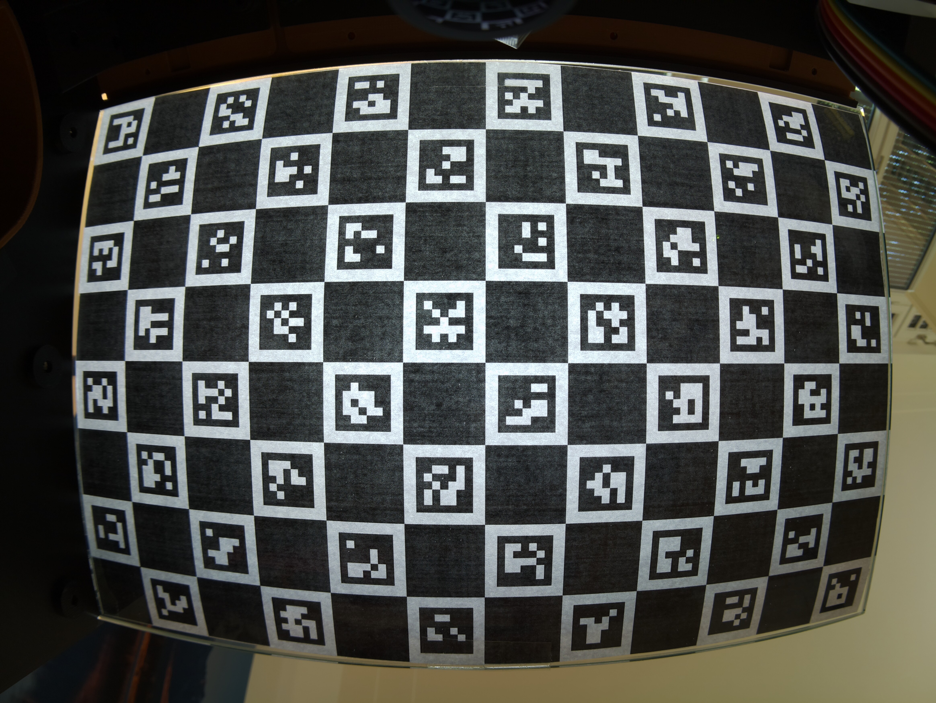
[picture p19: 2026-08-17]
calibration/shots/cam0_charuco_01.jpg

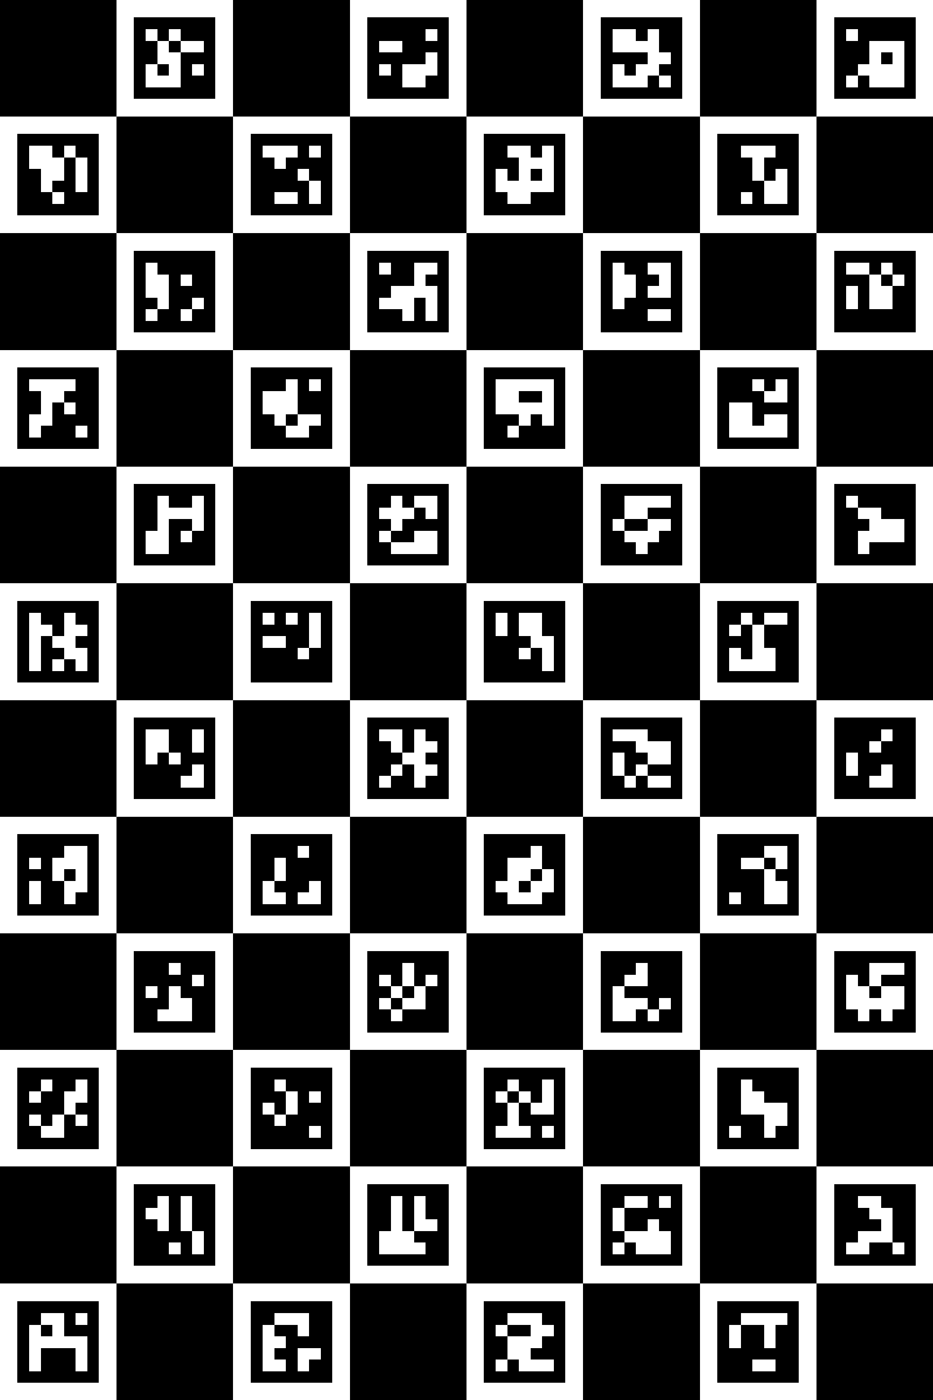
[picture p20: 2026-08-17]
calibration/out/charuco_160x240.png

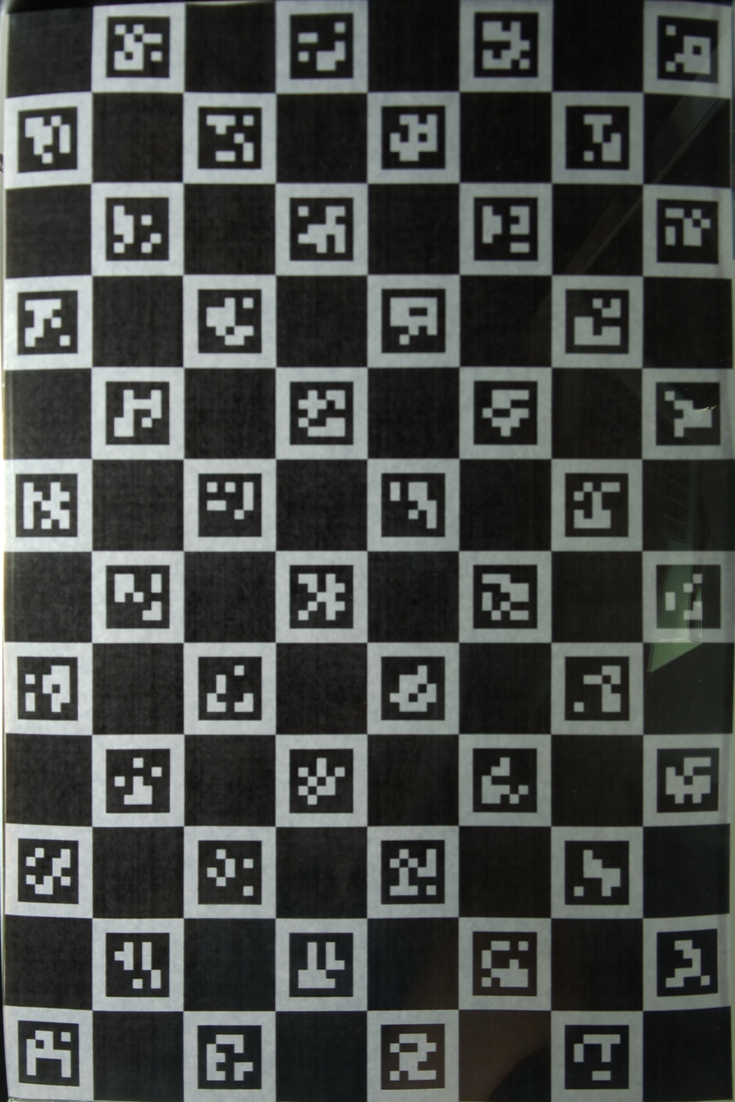
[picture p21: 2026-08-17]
calibration/out/cam1_charuco_01_rectified.jpg

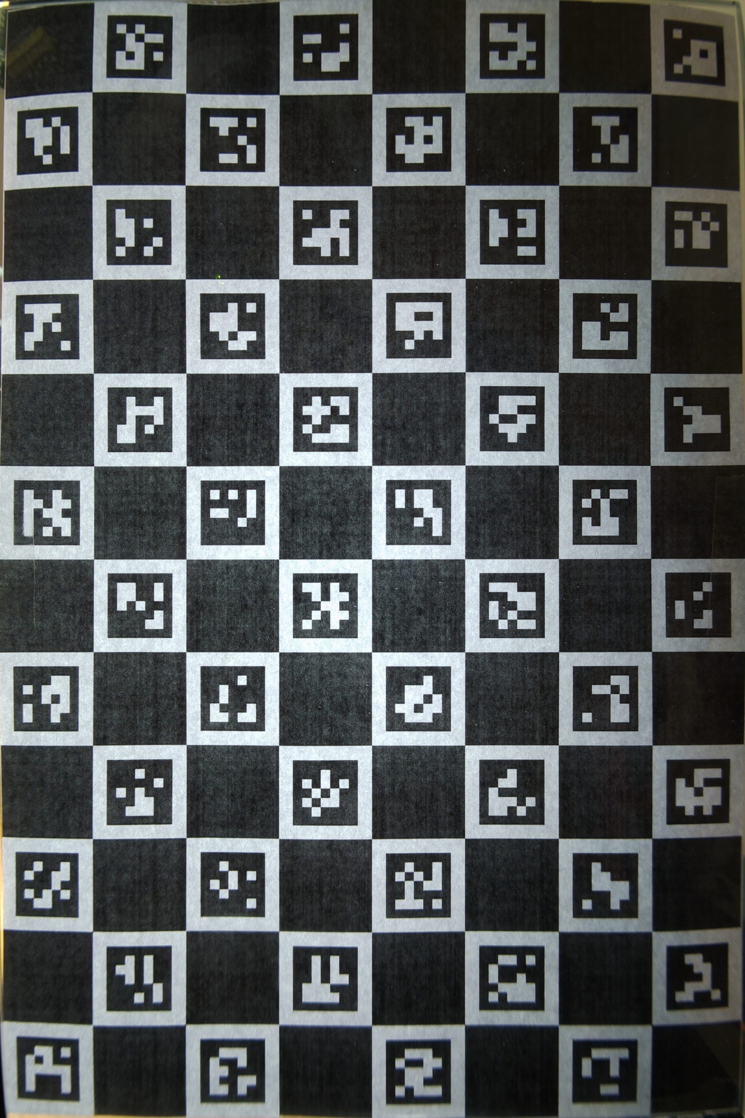
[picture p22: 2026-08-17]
calibration/out/cam0_charuco_01_rectified.jpg

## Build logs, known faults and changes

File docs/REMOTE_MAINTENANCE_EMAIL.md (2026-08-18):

# Remote Maintenance by E-Mail

Last reviewed: `2026-07-13`

Deutsche Fassung: [Fernwartung per E-Mail](../docs_DE/REMOTE_MAINTENANCE_EMAIL.md)

## Purpose

E-mail maintenance supplements SSH with two file-transfer paths:

- `email_download FILE` sends a local file to the `recipient` configured in
  the local `mail.ini`.
- A `systemd` timer checks every two minutes for messages not yet processed by
  ABR. A message from that configured recipient, with the subject
  `save PATH/` and exactly one attachment, stores the attachment under its
  attachment filename in the specified directory.

The implementation is located in `abr/remote_mail.py` and uses only the Python
standard library.

## Security Rules

- Account details are stored exclusively in `~/.config/abr/mail.ini` with
  mode `0600`, never in the repository.
- Uploads are accepted only from the exact sender configured locally as
  `recipient`.
- A message must contain exactly one attachment.
- The target directory must already exist. The filename is taken from the
  attachment and must not contain a path.
- An existing file is never overwritten; storage is atomic.
- Relative upload paths are resolved from the Pi user's home directory.
- Successfully processed upload messages are deleted from the IMAP mailbox
  only after the attachment has been stored safely. Messages already marked
  as read by another mail client are also detected.
- Processed IMAP UIDs are stored in
  `~/.local/state/abr/mail_upload.json`.
- Failed messages are not deleted and are retried on the next run regardless
  of their read status.

E-mail is not end-to-end encrypted. Do not transfer private keys, passwords,
or other secrets through this mechanism.

## Installation on the Raspberry Pi

From the current project directory:

```bash
cd ~/src/abr
sudo deploy/install_remote_mail.sh
```

On its first run, the installer creates `~/.config/abr/mail.ini` from
`deploy/mail.ini.example`. Complete the file with the e-mail address,
recipient, username, app password, and SMTP/IMAP settings for the selected
provider, then run the same installation command again. Real values remain
outside the repository and the file uses mode `0600`. Many providers require
a separate app password. SMTP and IMAP both use SSL/TLS.

The installer creates:

- `/usr/local/bin/email_download`
- `/etc/systemd/system/abr-email-upload.service`
- `/etc/systemd/system/abr-email-upload.timer`

## Usage

Send a file from the Pi:

```bash
cd ~/src/abr/captures/latest/raw
email_download cam0_raw.jpg
```

Upload a file to the Pi using an absolute home-relative form:

```text
Subject: save ~/src/abr/
Attachment: example.txt
```

Relative form, resolved from `~`:

```text
Subject: save src/abr/
Attachment: example.txt
```

Important: Enter only `save ...` in the actual subject field. The label
`Subject:` is not part of the subject.

## Verification and Diagnostics

```bash
email_download --help
systemctl status abr-email-upload.timer
sudo systemctl start abr-email-upload.service
journalctl -u abr-email-upload.service -n 50 --no-pager
```

An existing target file deliberately causes an error. After removing or
renaming that file, the message still present in the mailbox can be processed
on the next run.

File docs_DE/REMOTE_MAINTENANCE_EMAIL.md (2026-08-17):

# Fernwartung per E-Mail

Stand: `2026-07-13`

## Zweck

Die E-Mail-Wartung ergaenzt SSH um zwei Dateiwege:

- `email_download DATEI` sendet eine lokale Datei immer an den in der lokalen
  `mail.ini` eingetragenen Wert `recipient`.
- Ein `systemd`-Timer prueft alle zwei Minuten noch nicht vom ABR verarbeitete
  E-Mails. Eine Mail von diesem konfigurierten Empfaenger mit dem Betreff
  `save PFAD/` und genau einem
  Anhang speichert den Anhang unter seinem Anhangsnamen im angegebenen Ordner.

Die Implementierung liegt in `abr/remote_mail.py` und verwendet nur die
Python-Standardbibliothek.

## Sicherheitsregeln

- Die Kontodaten liegen ausschliesslich in `~/.config/abr/mail.ini` mit Modus
  `0600`, nicht im Repository.
- Uploads werden nur vom exakten, lokal als `recipient` konfigurierten
  Absender angenommen.
- Die Mail muss genau einen Anhang enthalten.
- Das Zielverzeichnis muss bereits existieren. Der Dateiname wird aus dem
  Anhang uebernommen und darf selbst keinen Pfad enthalten.
- Eine vorhandene Datei wird atomar niemals ueberschrieben.
- Relative Uploadpfade beziehen sich auf das Home-Verzeichnis des Pi-Benutzers.
- Erfolgreich verarbeitete Upload-Mails werden nach dem sicheren Speichern des
  Anhangs aus dem IMAP-Postfach geloescht. Bereits durch ein anderes
  Mailprogramm gelesene Nachrichten werden ebenfalls erkannt.
  Verarbeitete IMAP-UIDs stehen in `~/.local/state/abr/mail_upload.json`.
  Fehlgeschlagene Mails werden nicht geloescht und beim naechsten Lauf erneut
  versucht, unabhaengig von ihrem Gelesen-Status.

E-Mail ist nicht Ende-zu-Ende-verschluesselt. Deshalb keine privaten
Schluessel, Passwoerter oder andere Geheimnisse auf diesem Weg uebertragen.

## Installation auf dem Raspberry Pi

Im aktuellen Projektpfad:

```bash
cd ~/src/abr
sudo deploy/install_remote_mail.sh
```

Beim ersten Lauf wird `~/.config/abr/mail.ini` aus
`deploy/mail.ini.example` angelegt. Die Datei mit Mailadresse, Empfaenger,
Benutzername, App-Passwort sowie den SMTP-/IMAP-Daten des eigenen Anbieters
ausfuellen und denselben Installationsbefehl erneut starten. Die echten Werte
bleiben ausserhalb des Repositorys; die Datei hat Modus `0600`. Viele Anbieter
verlangen fuer diesen Zweck ein separates App-Passwort. SMTP und IMAP werden
mit SSL/TLS verwendet.

Der Installer erzeugt:

- `/usr/local/bin/email_download`
- `/etc/systemd/system/abr-email-upload.service`
- `/etc/systemd/system/abr-email-upload.timer`

## Benutzung

Download vom Pi:

```bash
cd ~/src/abr/captures/latest/raw
email_download cam0_raw.jpg
```

Upload zum Pi, absolute Variante:

```text
Betreff: save ~/src/abr/
Anhang: example.txt
```

Relative Variante, bezogen auf `~`:

```text
Betreff: save src/abr/
Anhang: example.txt
```

Wichtig: In das Betreff-Feld wird nur `save ...` eingetragen. Die
Beschriftung `Betreff:` ist nicht Teil des eigentlichen Mailbetreffs.

## Pruefung und Diagnose

```bash
email_download --help
systemctl status abr-email-upload.timer
sudo systemctl start abr-email-upload.service
journalctl -u abr-email-upload.service -n 50 --no-pager
```

Eine bereits vorhandene Zieldatei fuehrt absichtlich zu einem Fehler. Nach
dem Entfernen oder Umbenennen der Zieldatei kann die weiterhin vorhandene Mail
beim naechsten Lauf verarbeitet werden.

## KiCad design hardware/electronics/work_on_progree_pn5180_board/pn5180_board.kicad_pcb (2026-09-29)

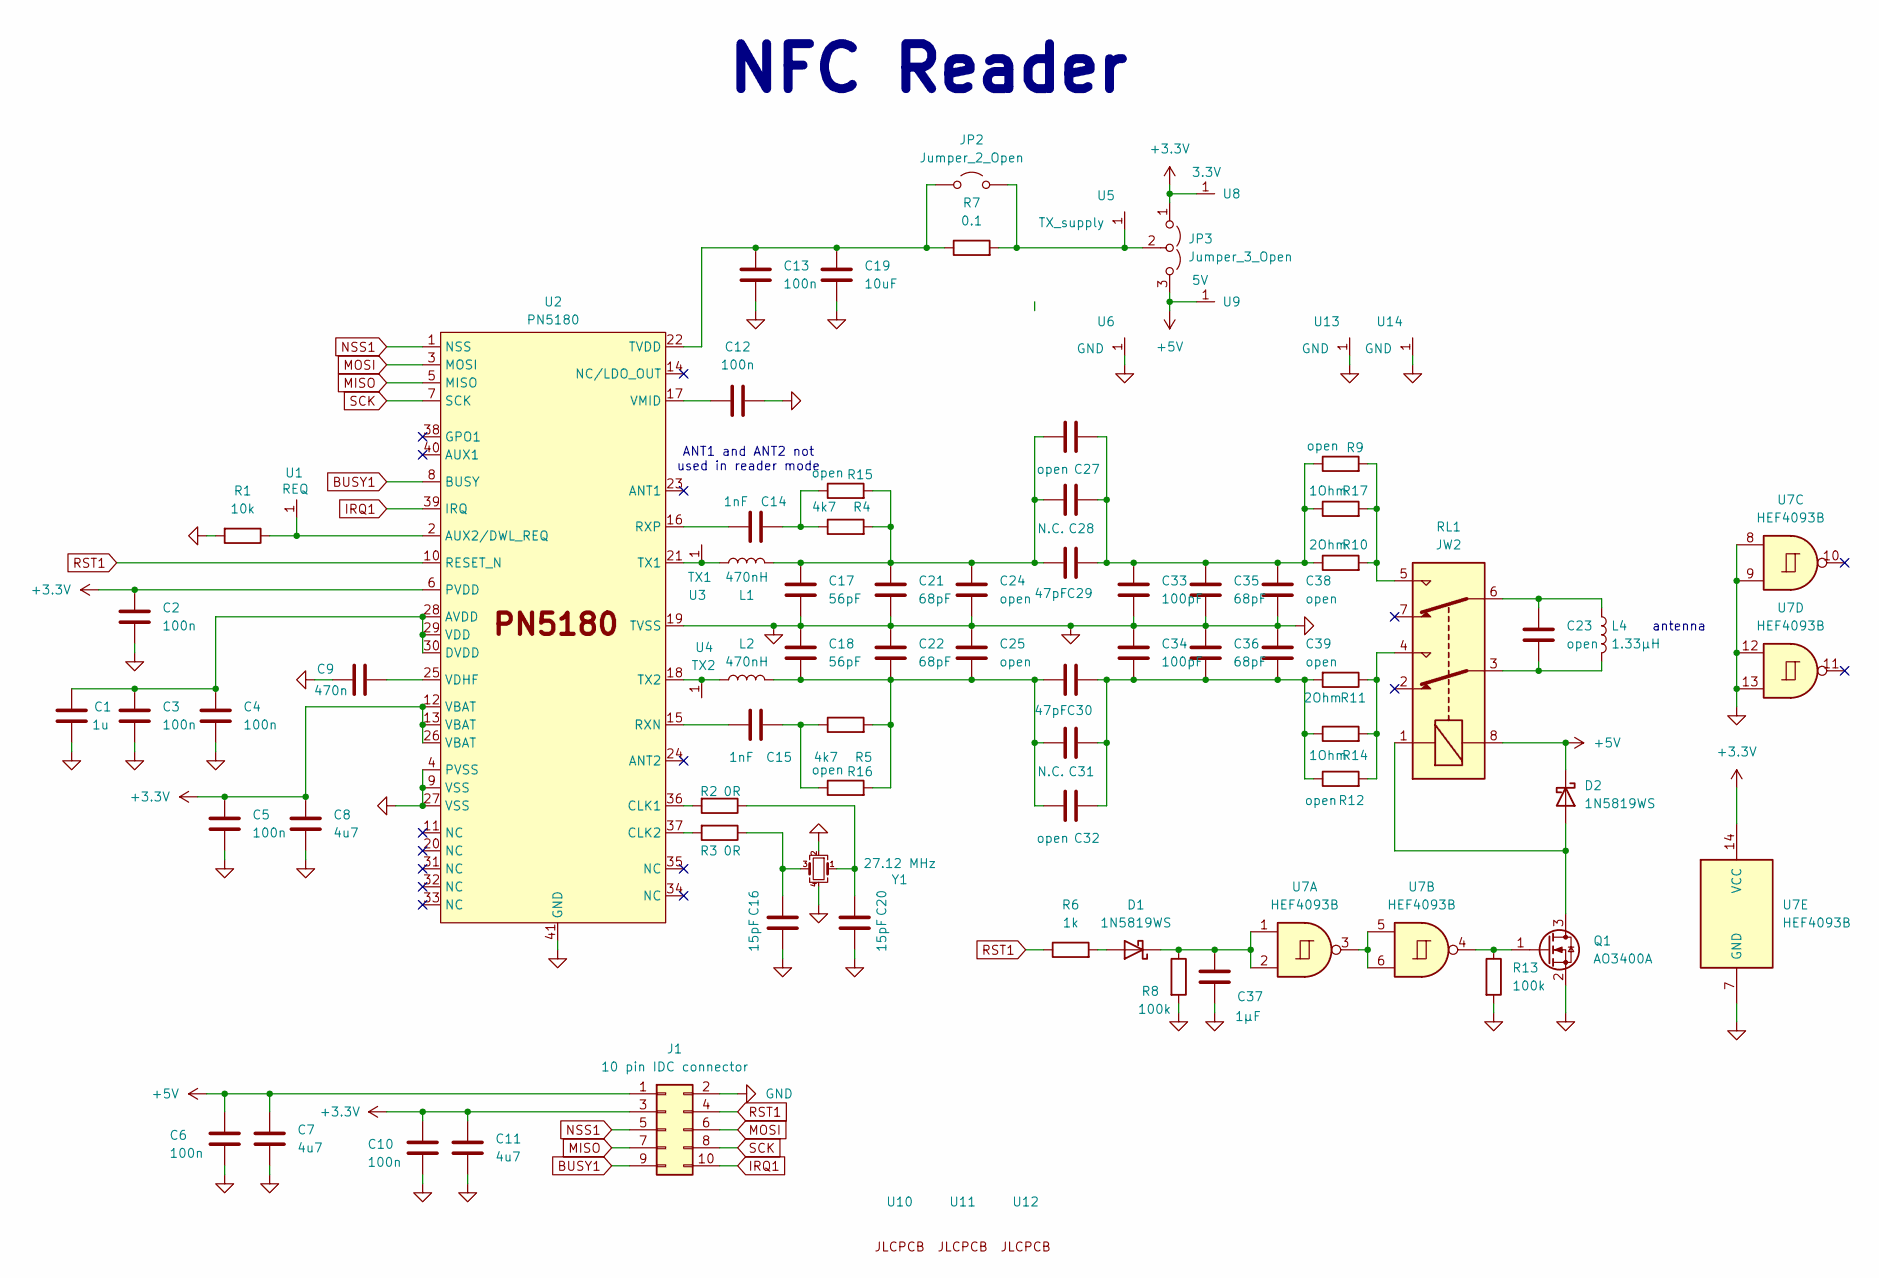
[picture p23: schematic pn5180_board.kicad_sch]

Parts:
C1: 1u; C_0603_1608Metric; LCSC C15849
C2, C3, C4, C5, C6, C10, C12, C13: 100n; C_0402_1005Metric; LCSC C1525
C7, C8, C11: 4u7; C_0603_1608Metric; LCSC C19666
C9: 470n; C_0603_1608Metric; LCSC C1623
C14, C15: 1nF; C_0402_1005Metric; LCSC C1523
C16, C20: 15pF; C_0402_1005Metric; LCSC C1548
C17, C18: 56pF; C_0603_1608Metric; LCSC C39148
C19: 10uF; C_0603_1608Metric; LCSC C96446
C21, C22, C35, C36: 68pF; C_0603_1608Metric; LCSC C28262
C23, C24, C25, C27, C32, C38, C39: open; C_aux
C28, C31: N.C.; C_0603_1608Metric
C29, C30: 47pF; C_0603_1608Metric; LCSC C1671
C33, C34: 100pF; C_0603_1608Metric; LCSC C14858
C37: 1µF; C_0603_1608Metric; LCSC C15849
D1, D2: 1N5819WS; D_SOD-323; LCSC C191023
J1: 10 pin IDC connector; IDC-Header_2x05_P2.54mm_Vertical_centered
JP2: Jumper_2_Open; SolderJumper-2_P1.3mm_Open_RoundedPad1.0x1.5mm
JP3: Jumper_3_Open; SolderJumper-3_P1.3mm_Open_RoundedPad1.0x1.5mm
L1, L2: 470nH; L_0603_1608Metric; LCSC C341701
L4: 1.33µH; NFC_antenna
Q1: AO3400A; SOT-23; LCSC C20917
R1: 10k; R_0402_1005Metric; LCSC C25744
R2, R3: 0R; R_0402_1005Metric; LCSC C17168
R4, R5: 4k7; R_0402_1005Metric; LCSC C25900
R6: 1k; R_0402_1005Metric; LCSC C11702
R7: 0.1; R_1206_3216Metric; LCSC C25334
R8, R13: 100k; R_0402_1005Metric; LCSC C25741
R9, R12, R15, R16: open; R_Axial_DIN0207_L6.3mm_D2.5mm_P10.16mm_Horizontal
R10, R11: 2Ohm; R_0603_1608Metric; LCSC C22977
R14, R17: 1Ohm; R_0603_1608Metric; LCSC C22936
RL1: JW2; Relay
U1: REQ; 1pin
U2: PN5180; HVQFN-40-1EP_6x6mm_P0.5mm_EP4.1x4.1mm_ThermalVias; LCSC C1526287
U3: TX1; 1pin
U4: TX2; 1pin
U5: TX_supply; 1pin
U6, U13, U14: GND; 1pin
U7: HEF4093B; SOIC-14_3.9x8.7mm_P1.27mm; LCSC C5456626
U8: 3.3V; 1pin
U9: 5V; 1pin
U10, U11, U12: JLC_tooling_hole
Y1: 27.12 MHz; Crystal_SMD_4Pin_A_3.2x2.5mm; LCSC C29975

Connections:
+3.3V: C2.1, C5.1, C8.1, C10.1, C11.1, J1.3, JP3.1 (A), U2.6 (PVDD), U2.12 (VBAT), U2.13 (VBAT), U2.26 (VBAT), U7.14 (VCC), U8.1 (pin)
+5V: C6.1, C7.1, D2.1 (K), J1.1, JP3.3 (B), RL1.8, U9.1 (pin)
BUSY1: J1.9, U2.8 (BUSY)
GND: C1.2, C2.2, C3.2, C4.2, C5.2, C6.2, C7.2, C8.2, C9.1, C10.2, C11.2, C12.2, C13.2, C16.2, C17.2, C18.1, C19.2, C20.2, C21.2, C22.1, C24.1, C25.2, C33.1, C34.2, C35.1, C36.2, C37.2, C38.1, C39.2, J1.2, Q1.2 (S), R1.2, R8.2, R13.2, U2.4 (PVSS), U2.9 (VSS), U2.19 (TVSS), U2.27 (VSS), U2.41 (GND), U6.1 (pin), U7.7 (GND), U7.8, U7.9, U7.12, U7.13, U13.1 (pin), U14.1 (pin), Y1.2, Y1.4
IRQ1: J1.10, U2.39 (IRQ)
MISO: J1.7, U2.5 (MISO)
MOSI: J1.6, U2.3 (MOSI)
NSS1: J1.5, U2.1 (NSS)
unnamed: C14.2, R4.1, R15.1
unnamed: C15.2, R5.1, R16.1
unnamed: C16.1, R3.1, Y1.3
unnamed: C17.1, C21.1, C24.2, C27.1, C28.1, C29.1, L1.2, R4.2, R15.2
unnamed: C18.2, C22.2, C25.1, C30.1, C31.1, C32.1, L2.2, R5.2, R16.2
unnamed: C20.1, R2.1, Y1.1
unnamed: C23.1, L4.2, RL1.3
unnamed: C23.2, L4.1, RL1.6
unnamed: C27.2, C28.2, C29.2, C33.2, C35.2, C38.2, R9.1, R10.1, R17.1
unnamed: C30.2, C31.2, C32.2, C34.1, C36.1, C39.1, R11.2, R12.1, R14.1
unnamed: D1.2 (A), R6.2
unnamed: C37.1, D1.1 (K), R8.1, U7.1, U7.2
unnamed: D2.2 (A), Q1.3 (D), RL1.1
unnamed: C13.1, C19.1, JP2.1 (A), R7.1, U2.22 (TVDD)
unnamed: JP2.2 (B), JP3.2 (C), R7.2, U5.1 (pin)
unnamed: Q1.1 (G), R13.1, U7.4
unnamed: R9.2, R10.2, R17.2, RL1.5
unnamed: R11.1, R12.2, R14.2, RL1.4
unnamed: R1.1, U1.1 (pin), U2.2 (AUX2/DWL_REQ)
unnamed: C1.1, C3.1, C4.1, U2.28 (AVDD), U2.29 (VDD), U2.30 (DVDD)
unnamed: R2.2, U2.36 (CLK1)
unnamed: R3.2, U2.37 (CLK2)
unnamed: C15.1, U2.15 (RXN)
unnamed: C14.1, U2.16 (RXP)
unnamed: L1.1, U2.21 (TX1), U3.1 (pin)
unnamed: L2.1, U2.18 (TX2), U4.1 (pin)
unnamed: C9.2, U2.25 (VDHF)
unnamed: C12.1, U2.17 (VMID)
unnamed: U7.3, U7.5, U7.6
RST1: J1.4, R6.1, U2.10 (RESET_N)
SCK: J1.8, U2.7 (SCK)

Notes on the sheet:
antenna
ANT1 and ANT2 not used in reader mode
NFC Reader

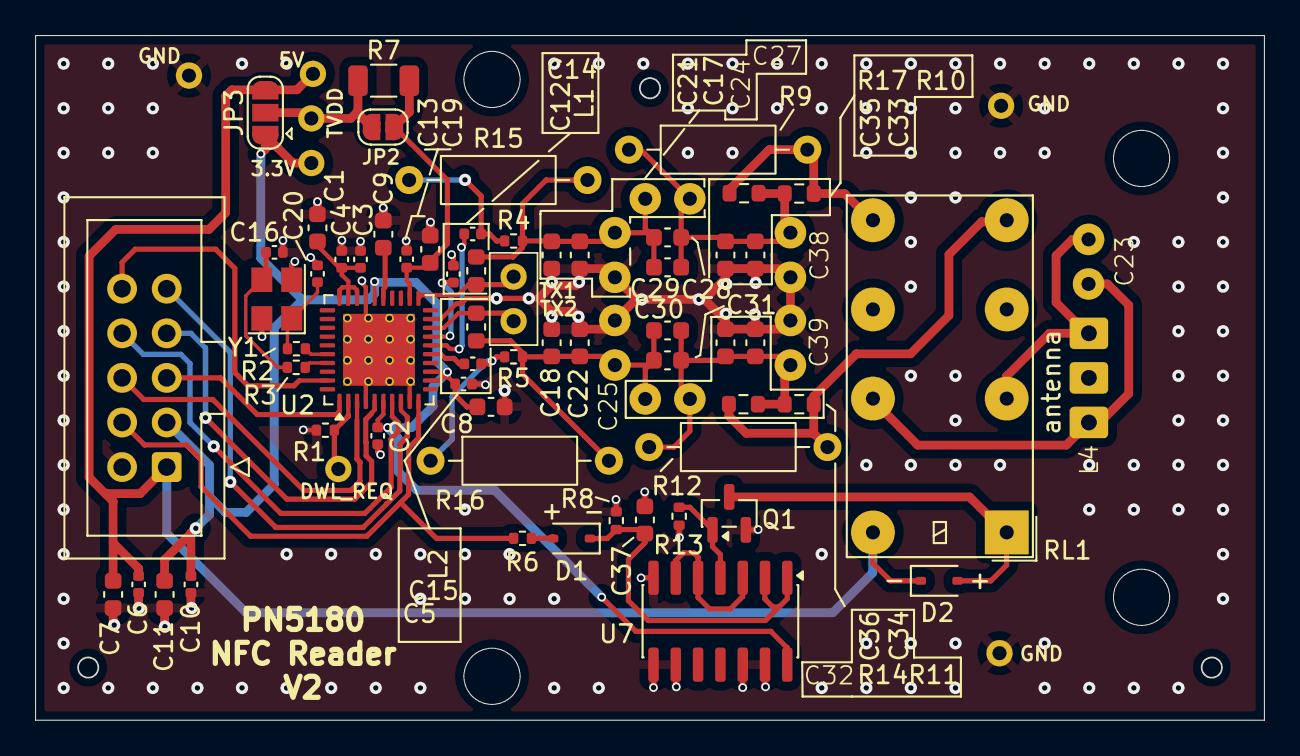
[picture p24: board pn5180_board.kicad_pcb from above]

Board: 2 copper layers, 70.0 x 39.0 mm, 80 parts (0 on the bottom side), 39 nets.

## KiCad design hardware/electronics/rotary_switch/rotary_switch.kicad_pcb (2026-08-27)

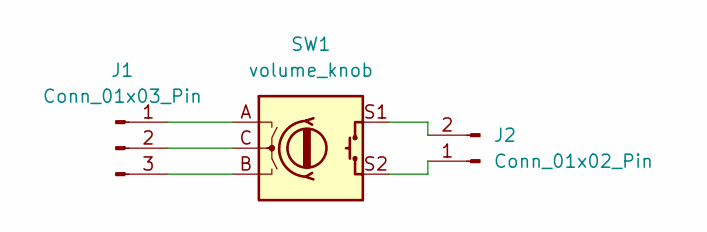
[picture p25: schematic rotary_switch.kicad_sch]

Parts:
J1: Conn_01x03_Pin; 3_pin
J2: Conn_01x02_Pin; 2_pin
SW1: volume_knob; RotaryEncoder_Alps_EC11E-Switch_Vertical_H20mm

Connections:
unnamed: J1.1, SW1.A
unnamed: J1.2, SW1.C
unnamed: J1.3, SW1.B
unnamed: J2.1, SW1.S2
unnamed: J2.2, SW1.S1

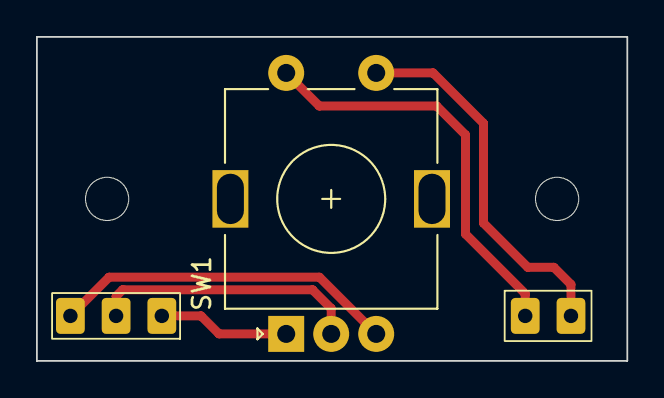
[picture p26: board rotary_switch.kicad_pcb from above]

Board: 2 copper layers, 32.8 x 18.0 mm, 3 parts (0 on the bottom side), 5 nets.

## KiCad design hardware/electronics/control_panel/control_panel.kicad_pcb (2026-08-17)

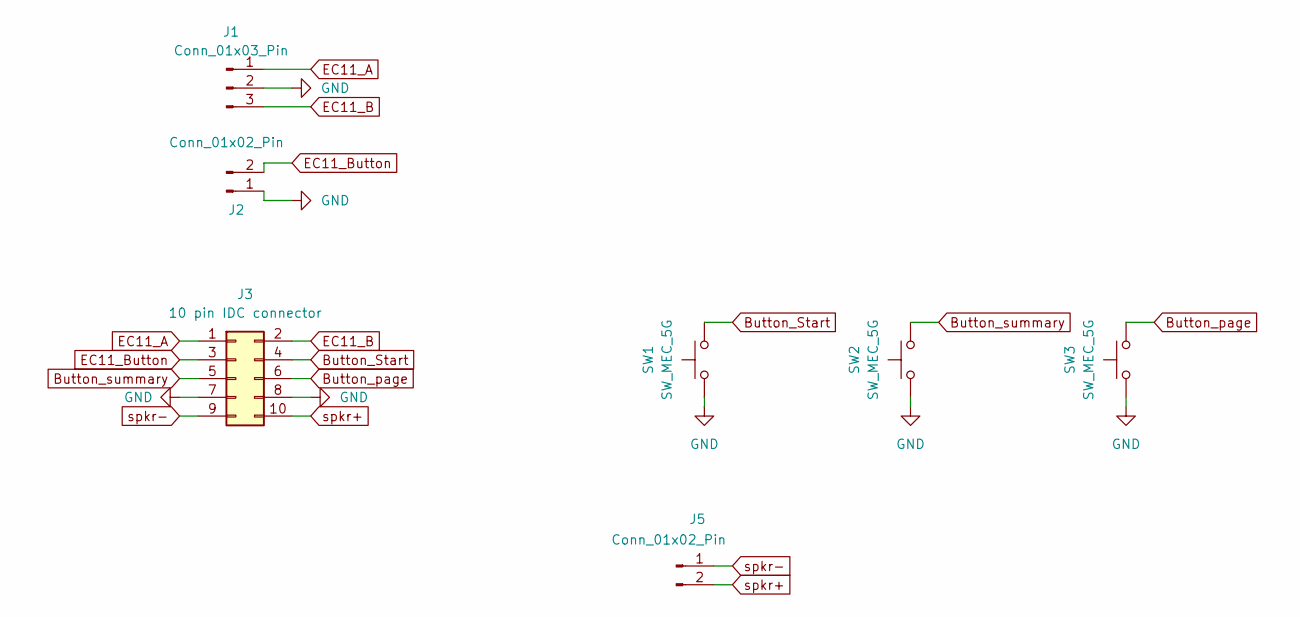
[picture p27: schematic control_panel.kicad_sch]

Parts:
J1: Conn_01x03_Pin; 3_pin
J2, J5: Conn_01x02_Pin; 2_pin
J3: 10 pin IDC connector; IDC-Header_2x05_P2.54mm_Vertical_centered
SW1, SW2, SW3: SW_MEC_5G; OmronTaster

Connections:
Button_Start: J3.4, SW1.2 (B)
Button_page: J3.6, SW3.2 (B)
Button_summary: J3.5, SW2.2 (B)
EC11_A: J1.1, J3.1
EC11_B: J1.3, J3.2
EC11_Button: J2.2, J3.3
GND: J1.2, J2.1, J3.7, J3.8, SW1.1 (A), SW2.1 (A), SW3.1 (A)
spkr+: J3.10, J5.2
spkr-: J3.9, J5.1

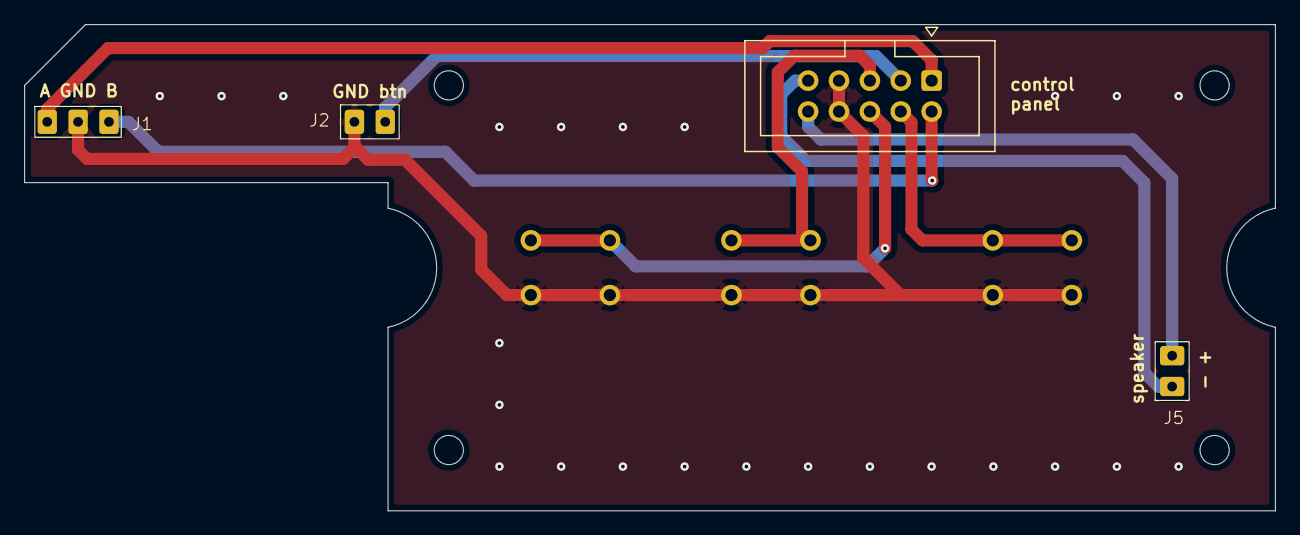
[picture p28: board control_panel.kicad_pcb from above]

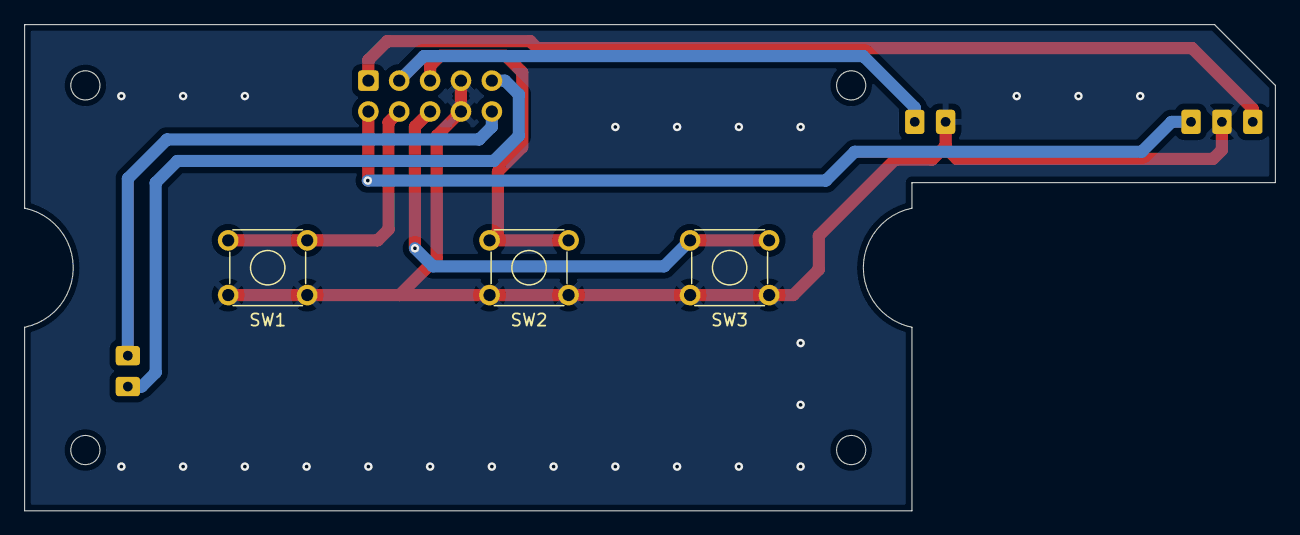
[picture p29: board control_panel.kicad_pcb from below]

Board: 2 copper layers, 102.9 x 40.0 mm, 7 parts (3 on the bottom side), 9 nets.

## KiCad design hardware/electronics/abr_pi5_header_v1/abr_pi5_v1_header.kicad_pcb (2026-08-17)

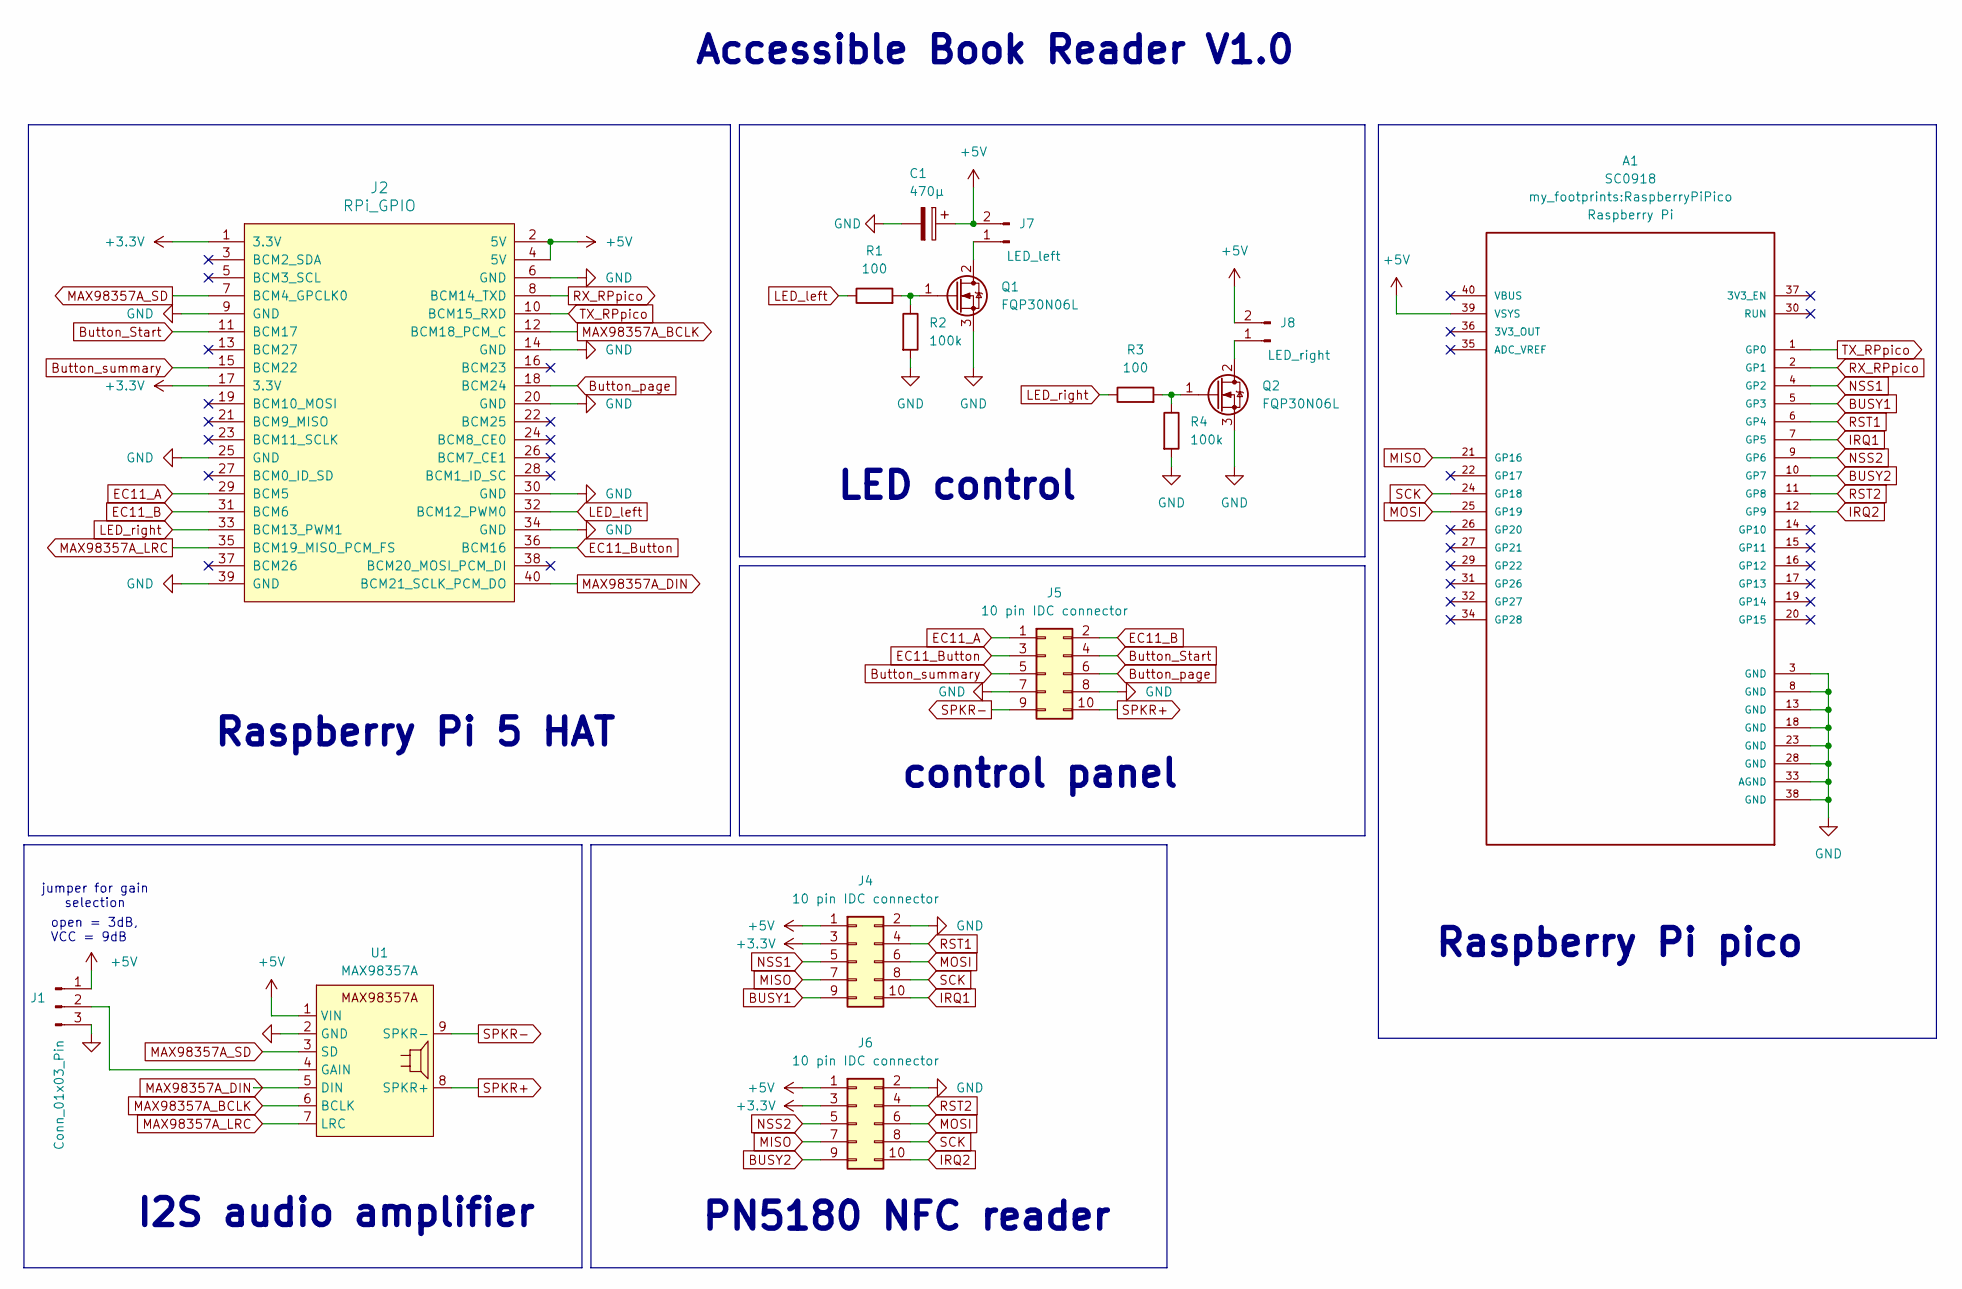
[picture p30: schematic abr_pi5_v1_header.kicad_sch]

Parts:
A1: SC0918; RaspberryPiPico; PARTREV 1.6
C1: 470µ; CP_Radial_D10.0mm_P5.00mm_slim_silkscreen
J1: Conn_01x03_Pin; 3_pin_jumper
J2: RPi_GPIO; RPI_HAT_back
J4, J5, J6: 10 pin IDC connector; IDC-Header_2x05_P2.54mm_Vertical_centered
J7: LED_left; JST_XH_B2B-XH-A_1x02_P2.50mm_Vertical
J8: LED_right; JST_XH_B2B-XH-A_1x02_P2.50mm_Vertical
Q1, Q2: FQP30N06L; TO220_vertikal
R1, R3: 100; R_Axial_DIN0207_L6.3mm_D2.5mm_P10.16mm_Horizontal
R2, R4: 100k; R_Axial_DIN0207_L6.3mm_D2.5mm_P10.16mm_Horizontal
U1: MAX98357A; MAX98357A_breakout

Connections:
+3.3V: J2.1 (3.3V), J2.17 (3.3V), J4.3, J6.3
+5V: A1.39 (VSYS), C1.1, J1.1, J2.2 (5V), J2.4 (5V), J4.1, J6.1, J7.2, J8.2, U1.1 (VIN)
BUSY1: A1.5 (GP3), J4.9
BUSY2: A1.10 (GP7), J6.9
Button_Start: J2.11 (BCM17), J5.4
Button_page: J2.18 (BCM24), J5.6
Button_summary: J2.15 (BCM22), J5.5
EC11_A: J2.29 (BCM5), J5.1
EC11_B: J2.31 (BCM6), J5.2
EC11_Button: J2.36 (BCM16), J5.3
GND: A1.3 (GND), A1.8 (GND), A1.13 (GND), A1.18 (GND), A1.23 (GND), A1.28 (GND), A1.33 (AGND), A1.38 (GND), C1.2, J1.3, J2.6 (GND), J2.9 (GND), J2.14 (GND), J2.20 (GND), J2.25 (GND), J2.30 (GND), J2.34 (GND), J2.39 (GND), J4.2, J5.7, J5.8, J6.2, Q1.3 (S), Q2.3 (S), R2.2, R4.2, U1.2 (GND)
IRQ1: A1.7 (GP5), J4.10
IRQ2: A1.12 (GP9), J6.10
LED_left: J2.32 (BCM12_PWM0), R1.1
LED_right: J2.33 (BCM13_PWM1), R3.1
MAX98357A_BCLK: J2.12 (BCM18_PCM_C), U1.6 (BCLK)
MAX98357A_DIN: J2.40 (BCM21_SCLK_PCM_DO), U1.5 (DIN)
MAX98357A_LRC: J2.35 (BCM19_MISO_PCM_FS), U1.7 (LRC)
MAX98357A_SD: J2.7 (BCM4_GPCLK0), U1.3 (SD)
MISO: A1.21 (GP16), J4.7, J6.7
MOSI: A1.25 (GP19), J4.6, J6.6
NSS1: A1.4 (GP2), J4.5
NSS2: A1.9 (GP6), J6.5
unnamed: J1.2, U1.4 (GAIN)
unnamed: J7.1, Q1.2 (D)
unnamed: J8.1, Q2.2 (D)
unnamed: Q1.1 (G), R1.2, R2.1
unnamed: Q2.1 (G), R3.2, R4.1
RST1: A1.6 (GP4), J4.4
RST2: A1.11 (GP8), J6.4
RX_RPpico: A1.2 (GP1), J2.8 (BCM14_TXD)
SCK: A1.24 (GP18), J4.8, J6.8
SPKR+: J5.10, U1.8 (SPKR+)
SPKR-: J5.9, U1.9 (SPKR-)
TX_RPpico: A1.1 (GP0), J2.10 (BCM15_RXD)

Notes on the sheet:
control panel
LED control
Accessible Book Reader V1.0
PN5180 NFC reader
jumper for gain selection
open = 3dB, VCC = 9dB
I2S audio amplifier
Raspberry Pi 5 HAT
Raspberry Pi pico

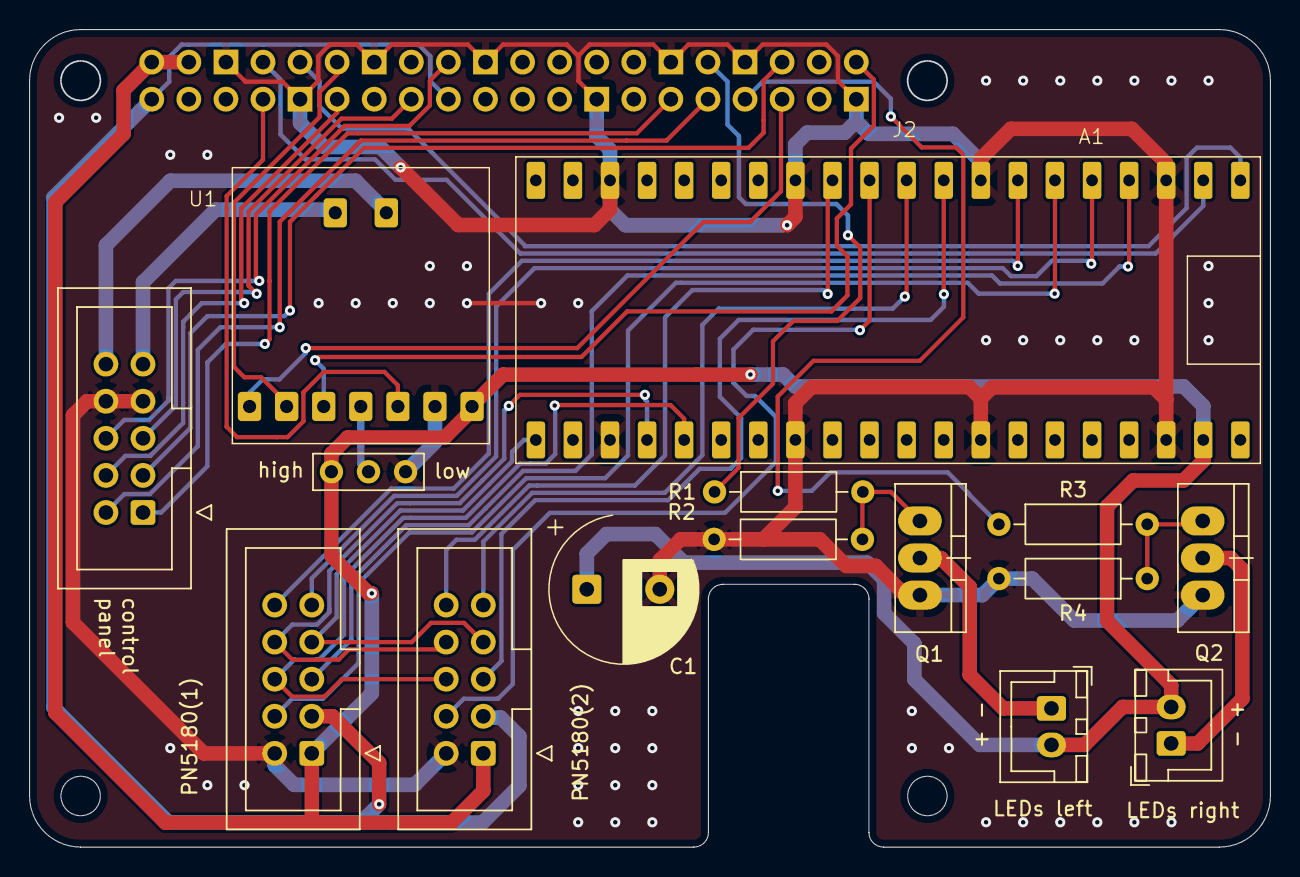
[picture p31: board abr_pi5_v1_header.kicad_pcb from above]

Board: 2 copper layers, 85.0 x 56.0 mm, 16 parts (0 on the bottom side), 35 nets.

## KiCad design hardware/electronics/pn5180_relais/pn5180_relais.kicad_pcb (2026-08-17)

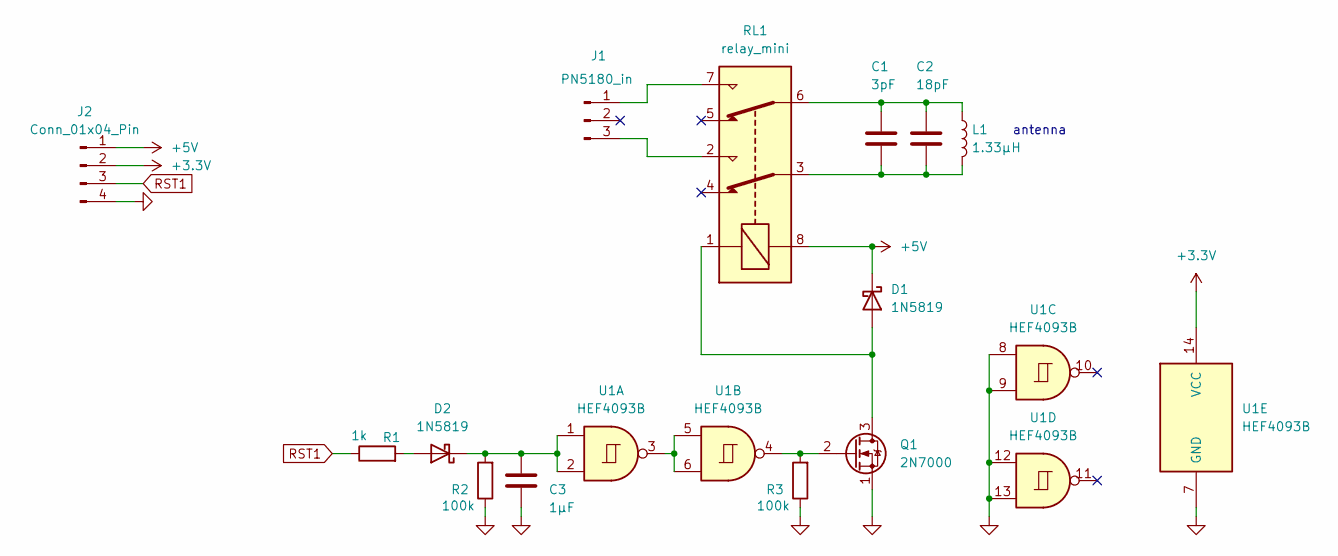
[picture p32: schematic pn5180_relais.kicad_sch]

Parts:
C1: 3pF; C_aux; LCSC C1653
C2: 18pF; C_aux; LCSC C1653
C3: 1µF; CP_Radial_D4.0mm_P1.50mm
D1, D2: 1N5819; D_A-405_P7.62mm_Horizontal; LCSC C191023
J1: PN5180_in; 3_pin_hori
J2: Conn_01x04_Pin; 4_pin
L1: 1.33µH; NFC_antenna
Q1: 2N7000; TO-92_Inline
R1: 1k; R_Axial_DIN0207_L6.3mm_D2.5mm_P10.16mm_Horizontal
R2, R3: 100k; R_Axial_DIN0207_L6.3mm_D2.5mm_P10.16mm_Horizontal
RL1: relay_mini; Relay
U1: HEF4093B; DIP-14_W7.62mm; LCSC C5456626

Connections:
+3.3V: J2.2, U1.14 (VCC)
+5V: D1.1 (K), J2.1, RL1.8
GND: C3.2, J2.4, Q1.1 (S), R2.1, R3.1, U1.7 (GND), U1.8, U1.9, U1.12, U1.13
unnamed: C1.1, C2.1, L1.2, RL1.3
unnamed: C1.2, C2.2, L1.1, RL1.6
unnamed: D1.2 (A), Q1.3 (D), RL1.1
unnamed: D2.2 (A), R1.2
unnamed: C3.1, D2.1 (K), R2.2, U1.1, U1.2
unnamed: J1.1, RL1.7
unnamed: J1.3, RL1.2
unnamed: Q1.2 (G), R3.2, U1.4
unnamed: U1.3, U1.5, U1.6
RST1: J2.3, R1.1

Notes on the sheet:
antenna

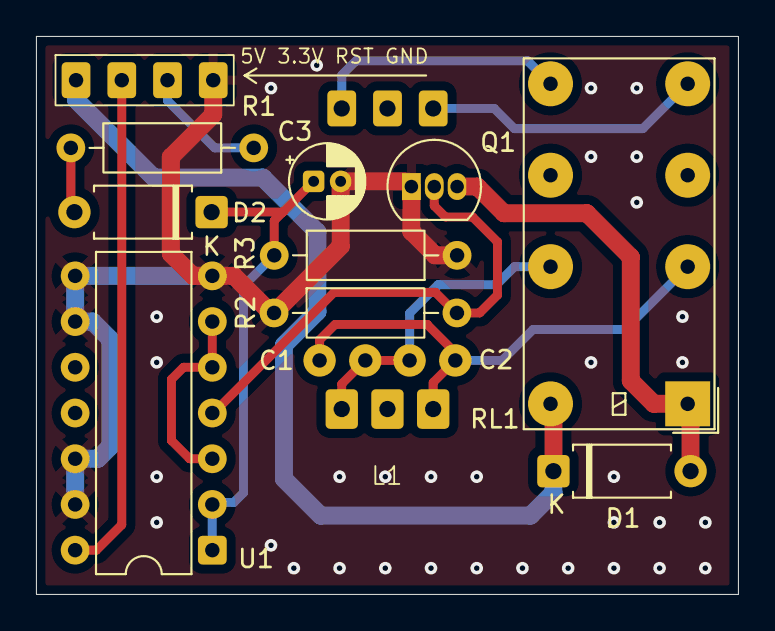
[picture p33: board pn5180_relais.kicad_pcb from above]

Board: 2 copper layers, 39.0 x 31.0 mm, 14 parts (1 on the bottom side), 13 nets.

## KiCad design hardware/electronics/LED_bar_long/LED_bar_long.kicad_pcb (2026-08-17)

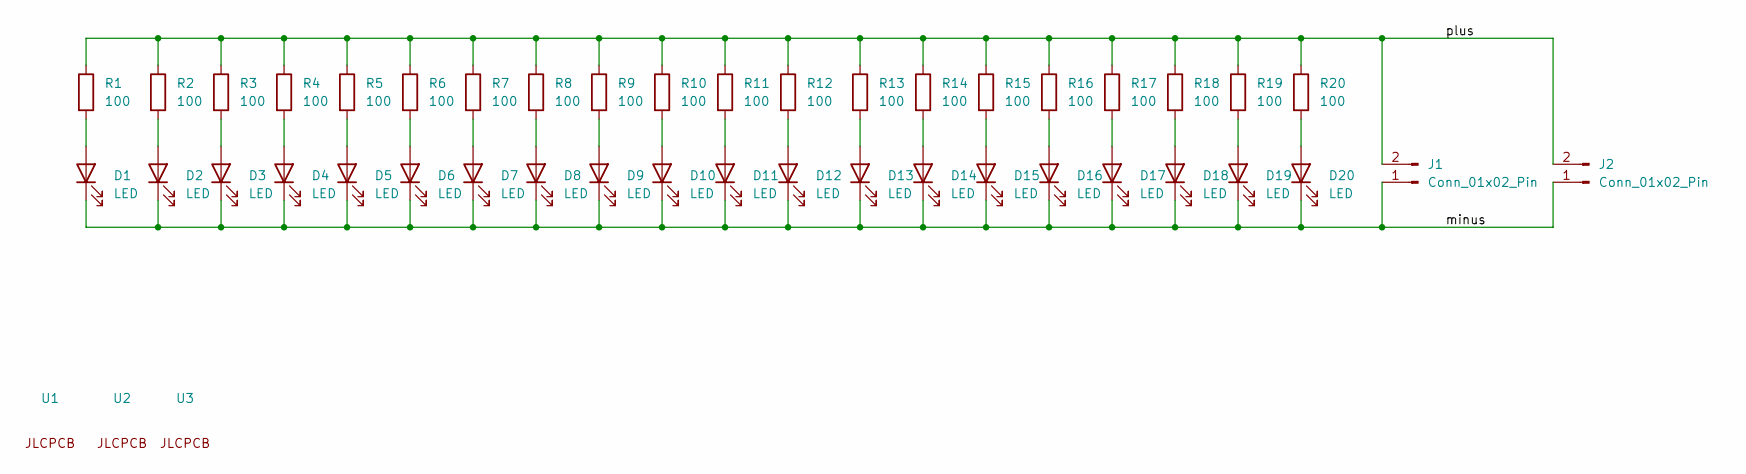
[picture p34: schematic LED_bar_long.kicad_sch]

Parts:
D1, D2, D3, D4, D5, D6, D7, D8, D9, D10, D11, D12, D13, D14, D15, D16, D17, D18, D19, D20: LED; LED_1206; LCSC C219234
J1, J2: Conn_01x02_Pin; 2_pin
R1, R2, R3, R4, R5, R6, R7, R8, R9, R10, R11, R12, R13, R14, R15, R16, R17, R18, R19, R20: 100; R_1206_3216Metric; LCSC C17901
U1, U2, U3: JLC_tooling_hole

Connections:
/minus: D1.1 (K), D2.1 (K), D3.1 (K), D4.1 (K), D5.1 (K), D6.1 (K), D7.1 (K), D8.1 (K), D9.1 (K), D10.1 (K), D11.1 (K), D12.1 (K), D13.1 (K), D14.1 (K), D15.1 (K), D16.1 (K), D17.1 (K), D18.1 (K), D19.1 (K), D20.1 (K), J1.1, J2.1
/plus: J1.2, J2.2, R1.1, R2.1, R3.1, R4.1, R5.1, R6.1, R7.1, R8.1, R9.1, R10.1, R11.1, R12.1, R13.1, R14.1, R15.1, R16.1, R17.1, R18.1, R19.1, R20.1
unnamed: D1.2 (A), R1.2
unnamed: D2.2 (A), R2.2
unnamed: D3.2 (A), R3.2
unnamed: D4.2 (A), R4.2
unnamed: D5.2 (A), R5.2
unnamed: D6.2 (A), R6.2
unnamed: D7.2 (A), R7.2
unnamed: D8.2 (A), R8.2
unnamed: D9.2 (A), R9.2
unnamed: D10.2 (A), R10.2
unnamed: D11.2 (A), R11.2
unnamed: D12.2 (A), R12.2
unnamed: D13.2 (A), R13.2
unnamed: D14.2 (A), R14.2
unnamed: D15.2 (A), R15.2
unnamed: D16.2 (A), R16.2
unnamed: D17.2 (A), R17.2
unnamed: D18.2 (A), R18.2
unnamed: D19.2 (A), R19.2
unnamed: D20.2 (A), R20.2


Board: 2 copper layers, 230.0 x 10.0 mm, 45 parts (0 on the bottom side), 22 nets.

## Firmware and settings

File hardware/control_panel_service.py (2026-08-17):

#!/usr/bin/env python3
from __future__ import annotations

import argparse
import sys
import time
from pathlib import Path


PROJECT_ROOT = Path(__file__).resolve().parents[1]
if str(PROJECT_ROOT) not in sys.path:
    sys.path.insert(0, str(PROJECT_ROOT))

from abr.control import (
    ABRAction,
    ABRActionType,
    AudioVolumeConfig,
    AudioVolumeController,
    ArtifactCleanupConfig,
    CaptureOCRJobConfig,
    ForegroundJobManager,
    PageAudioPlayer,
    PageSpeechConfig,
    FrontPanelConfig,
    FrontPanelMonitor,
    PageIngestRuntimeConfig,
    RuntimeController,
    build_page_ingest_service,
)
from abr.book import (
    BookStore,
    ChapterAssembler,
    GeminiSummaryBackend,
    GeminiSummaryConfig,
    SummaryManager,
    SummaryManagerConfig,
)
from abr.hardware.nfc_gateway import GatewayNFCTagReader, NFCGatewayConfig
from abr.hardware.pico_gateway_client import DEFAULT_DEVICE as DEFAULT_NFC_DEVICE
from abr.control.frontpanel import FrontPanelButtonConfig, FrontPanelEncoderEvent
from abr.usage_statistics import UsageStatisticsStore
from abr.language_config import DEFAULT_CONFIG_PATH as DEFAULT_LANGUAGE_CONFIG_PATH
from abr.language_config import LanguageConfigStore, LanguageProfile
from abr.system_audio import SystemAudioConfig


def _build_parser() -> argparse.ArgumentParser:
    parser = argparse.ArgumentParser(
        description="Dauerhafter Frontpanel-Monitor fuer Taster und EC11 des ABR-Projekts."
    )
    parser.add_argument(
        "--gpio-backend",
        choices=("auto", "rpi-gpio", "pinctrl"),
        default="auto",
        help="GPIO-Backend fuer den direkten Pi-Zugriff, Standard: auto.",
    )
    parser.add_argument(
        "--poll-interval-ms",
        type=float,
        default=2.0,
        help="Normales Polling-Intervall in Millisekunden, Standard: 2.0.",
    )
    parser.add_argument(
        "--active-poll-interval-ms",
        type=float,
        default=0.5,
        help="Schnelles Polling waehrend Encoder-Aktivitaet, Standard: 0.5.",
    )
    parser.add_argument(
        "--encoder-active-hold-ms",
        type=float,
        default=25.0,
        help="Wie lange nach Encoder-Flanken schnell gepollt wird, Standard: 25.",
    )
    parser.add_argument(
        "--button-debounce-ms",
        type=float,
        default=25.0,
        help="Debounce-Zeit fuer alle Taster in Millisekunden, Standard: 25.",
    )
    parser.add_argument(
        "--job-mode",
        choices=("dummy", "capture-ocr"),
        default="capture-ocr",
        help="Welcher Start/Stop-Job ausgefuehrt wird, Standard: capture-ocr.",
    )
    parser.add_argument(
        "--dummy-job-seconds",
        type=float,
        default=8.0,
        help="Dauer des Dummy-Capture/OCR-Jobs in Sekunden, Standard: 8.0.",
    )
    parser.add_argument(
        "--capture-output-root",
        type=Path,
        default=Path("captures"),
        help="Ausgabewurzel fuer capture_double_page.py, Standard: captures",
    )
    parser.add_argument(
        "--ocr-output-dir",
        type=Path,
        default=Path("runs/latest_rapidocr"),
        help="Ausgabeverzeichnis fuer run_rapidocr.py, Standard: runs/latest_rapidocr",
    )
    parser.add_argument(
        "--orientation-mode",
        choices=("off", "simple"),
        default="off",
        help="Orientierungsmodus fuer run_rapidocr.py, Standard: off.",
    )
    parser.add_argument(
        "--overlay",
        action="store_true",
        help="OCR-Overlay-Bilder fuer run_rapidocr.py erzeugen.",
    )
    parser.add_argument(
        "--capture-timeout-ms",
        type=int,
        help="Optionaler Capture-Timeout fuer capture_double_page.py.",
    )
    parser.add_argument(
        "--keep-denoise",
        action="store_true",
        help="De-Noising im Capture/OCR-Pfad aktiv lassen. Standard ist --no-denoise.",
    )
    parser.add_argument(
        "--library-root",
        type=Path,
        default=Path("library"),
        help="Buchdaten-Wurzel fuer PageIngestor, Standard: library",
    )
    parser.add_argument(
        "--book-tag-id",
        default="TESTBOOK",
        help="Fallback-Buch-ID, wenn NFC explizit deaktiviert ist. Standard: TESTBOOK",
    )
    parser.add_argument(
        "--nfc-mode",
        choices=("gateway", "disabled"),
        default="gateway",
        help="Quelle fuer Buch-Tags. Standard: gateway.",
    )
    parser.add_argument(
        "--nfc-device",
        default=DEFAULT_NFC_DEVICE,
        help=f"UART-Geraet fuer das NFC-Gateway, Standard: {DEFAULT_NFC_DEVICE}",
    )
    parser.add_argument(
        "--nfc-baud",
        type=int,
        default=115200,
        help="Baudrate fuer das NFC-Gateway, Standard: 115200.",
    )
    parser.add_argument(
        "--nfc-timeout",
        type=float,
        default=10.0,
        help="Timeout fuer NFC-Statusabfrage inklusive STATUS_FETCH in Sekunden, Standard: 10.0.",
    )
    parser.add_argument(
        "--iso15693-only-orientation",
        choices=("reader1", "reader2"),
        default="reader2",
        help=(
            "Orientierung bei Zuordnung nur ueber ISO15693: reader2 behaelt die "
            "Links-/Rechts-Zuordnung, reader1 vertauscht beide Seiten. Die "
            "Seiten werden nicht zusaetzlich gedreht. Standard: reader2."
        ),
    )
    parser.add_argument(
        "--artifact-mode",
        choices=("debug", "production"),
        default="debug",
        help="Artefaktmodus: debug behaelt alles, production raeumt auf. Standard: debug.",
    )
    parser.add_argument(
        "--cleanup-stage",
        choices=("after-ocr", "after-ingest"),
        default="after-ingest",
        help="Wann in production aufgeraeumt wird. Standard: after-ingest.",
    )
    parser.add_argument(
        "--volume-mixer-control",
        default="auto",
        help="Mixer-Control fuer die EC11-Lautstaerkeregelung, Standard: auto.",
    )
    parser.add_argument(
        "--language-config",
        type=Path,
        default=DEFAULT_LANGUAGE_CONFIG_PATH,
        help="Persistente Buchsprachenkonfiguration, Standard: ~/.config/abr/device.json.",
    )
    parser.add_argument(
        "--page-tts-backend",
        choices=("google", "google-standard-enhanced", "google-neural2", "google-gemini-flash"),
        default="google",
        help=(
            "TTS-Pfad fuer Buchseiten: google nutzt die Standardstimme des Sprachprofils; "
            "google-standard-enhanced nutzt dieselbe Stimme mit erweiterter SSML-Aufbereitung; "
            "google-neural2 und google-gemini-flash aktivieren getrennte "
            "Versuchspfade. Standard: google."
        ),
    )
    parser.add_argument(
        "--page-tts-speed",
        type=float,
        default=0.9,
        help="Sprechgeschwindigkeit fuer die Seitenausgabe, Standard: 0.9.",
    )
    parser.add_argument(
        "--google-standard-voice-name",
        help="Optionale abweichende Google-Standardstimme; Standard kommt aus dem Sprachprofil.",
    )
    parser.add_argument(
        "--google-neural2-voice-name",
        help="Optionale Neural2-Stimme; Standard kommt aus dem Sprachprofil.",
    )
    parser.add_argument(
        "--google-gemini-flash-voice-name",
        default="Charon",
        help="Stimme fuer Gemini 2.5 Flash TTS, Standard: Charon.",
    )
    parser.add_argument(
        "--google-gemini-flash-prompt",
        help="Optionale Stilanweisung; Standard kommt aus dem Sprachprofil.",
    )
    parser.add_argument(
        "--summary-gemini-model",
        default="gemini-3.5-flash",
        help="Gemini-Modell fuer Kapitel- und Buchzusammenfassungen, Standard: gemini-3.5-flash.",
    )
    parser.add_argument(
        "--summary-gcp-project",
        help="Optionales Google-Cloud-Projekt fuer Gemini-Zusammenfassungen. Standard: ADC/gcloud-Projekt.",
    )
    parser.add_argument(
        "--summary-gcp-location",
        default="global",
        help="Google-Cloud-Location fuer Gemini-Zusammenfassungen, Standard: global.",
    )
    parser.add_argument(
        "--chapter-summary-target-pages",
        type=float,
        default=1.5,
        help=(
            "Zielgroesse fuer Kapitelzusammenfassungen; eine Textseite entspricht "
            "250 Woertern. Standard: 1.5."
        ),
    )
    parser.add_argument(
        "--book-summary-target-pages",
        type=float,
        default=1.5,
        help=(
            "Zielgroesse fuer 'Was bisher geschah'; eine Textseite entspricht "
            "250 Woertern. Standard: 1.5."
        ),
    )
    return parser


def _timestamp() -> str:
    return time.strftime("%H:%M:%S")


def _print_status(message: str) -> None:
    print(f"[{_timestamp()}] {message}", flush=True)


def _describe_action(action: ABRAction) -> str:
    if action.action_type == ABRActionType.DELETE_BOOK_REQUEST:
        return "Benutzereingabe: Dreifachtaste fuer Buch-Loeschen gedrueckt"
    if action.action_type == ABRActionType.START_STOP:
        return "Benutzereingabe: Start / Stop / NFC gedrueckt"
    if action.action_type == ABRActionType.BOOK_SUMMARY:
        return "Benutzereingabe: Buch-Zusammenfassung gedrueckt"
    if action.action_type == ABRActionType.CHAPTER_SUMMARY:
        return "Benutzereingabe: Kapitel-/Letzte-Seiten-Zusammenfassung gedrueckt"
    if action.action_type == ABRActionType.ENCODER_BUTTON:
        return "Benutzereingabe: EC11-Taster gedrueckt"
    if action.action_type == ABRActionType.VOLUME_DELTA:
        assert action.value is not None
        direction = "rechts" if action.value > 0 else "links"
        steps = abs(action.value)
        encoder_event = action.source_event
        position_text = ""
        if isinstance(encoder_event, FrontPanelEncoderEvent):
            position_text = f", Position {encoder_event.position}"
        if steps == 1:
            return f"Benutzereingabe: EC11 1 Rasterung nach {direction}{position_text}"
        return f"Benutzereingabe: EC11 {steps} Rasterungen nach {direction}{position_text}"
    return f"Benutzereingabe: {action.source_event.label}"


def _print_action(action: ABRAction) -> None:
    print(f"[{_timestamp()}] {_describe_action(action)}", flush=True)


def _build_page_speech_config(
    args: argparse.Namespace,
    language_profile: LanguageProfile,
) -> PageSpeechConfig:
    return PageSpeechConfig(
        language_code=language_profile.code,
        chapter_label=language_profile.chapter_label,
        tts_backend=args.page_tts_backend,
        tts_speed=args.page_tts_speed,
        elevenlabs_language_code=language_profile.elevenlabs_language_code,
        google_tts_voice_name=(
            args.google_standard_voice_name
            or language_profile.google_standard_voice_name
        ),
        google_tts_language_code=language_profile.google_tts_language_code,
        google_neural2_voice_name=(
            args.google_neural2_voice_name
            or language_profile.google_neural2_voice_name
        ),
        google_gemini_flash_voice_name=args.google_gemini_flash_voice_name,
        google_gemini_flash_prompt=(
            args.google_gemini_flash_prompt
            or language_profile.google_gemini_flash_prompt
        ),
    )


def _build_system_audio_config(language_profile: LanguageProfile) -> SystemAudioConfig:
    return SystemAudioConfig(
        root_dir=PROJECT_ROOT / "system_audio" / "messages" / language_profile.code,
    )


def main() -> int:
    args = _build_parser().parse_args()
    if min(
        args.poll_interval_ms,
        args.active_poll_interval_ms,
        args.encoder_active_hold_ms,
        args.button_debounce_ms,
        args.dummy_job_seconds,
    ) <= 0:
        print("Fehler: Alle Zeitparameter muessen > 0 sein.", file=sys.stderr)
        return 1
    if args.capture_timeout_ms is not None and args.capture_timeout_ms < 0:
        print("Fehler: --capture-timeout-ms darf nicht negativ sein.", file=sys.stderr)
        return 1
    if args.nfc_baud <= 0 or args.nfc_timeout <= 0:
        print("Fehler: --nfc-baud und --nfc-timeout muessen > 0 sein.", file=sys.stderr)
        return 1
    if args.page_tts_speed <= 0:
        print("Fehler: --page-tts-speed muss > 0 sein.", file=sys.stderr)
        return 1

    try:
        language_profile = LanguageConfigStore(args.language_config).load()
    except RuntimeError as exc:
        print(f"Fehler: {exc}", file=sys.stderr)
        return 1
    _print_status(
        f"Buchsprache: {language_profile.display_name} ({language_profile.code}); "
        f"TTS {language_profile.google_tts_language_code}."
    )

    config = FrontPanelConfig(
        gpio_backend=args.gpio_backend,
        poll_interval_ms=args.poll_interval_ms,
        active_poll_interval_ms=args.active_poll_interval_ms,
        encoder_active_hold_ms=args.encoder_active_hold_ms,
        buttons=tuple(
            FrontPanelButtonConfig(
                name=button.name,
                label=button.label,
                pin=button.pin,
                debounce_ms=args.button_debounce_ms,
            )
            for button in FrontPanelConfig().buttons
        ),
    )
    monitor = FrontPanelMonitor(config=config, status_callback=_print_status)
    job_manager = ForegroundJobManager()
    artifact_cleanup = ArtifactCleanupConfig(
        mode=args.artifact_mode,
        stage=args.cleanup_stage,
    )
    capture_ocr_config = CaptureOCRJobConfig(
        python_executable=sys.executable,
        project_root=PROJECT_ROOT,
        capture_output_root=args.capture_output_root,
        ocr_output_dir=args.ocr_output_dir,
        capture_timeout_ms=args.capture_timeout_ms,
        no_denoise=not args.keep_denoise,
        overlay=args.overlay,
        orientation_mode=args.orientation_mode,
        language=language_profile.ocr_language,
        iso15693_only_orientation=args.iso15693_only_orientation,
        artifact_cleanup=artifact_cleanup,
    )
    page_ingest_service = build_page_ingest_service(
        library_root=args.library_root,
        capture_ocr_config=capture_ocr_config,
        language_code=language_profile.code,
        status_callback=lambda message: _print_status(f"ingest: {message}"),
    )
    book_store = BookStore(args.library_root.expanduser().resolve())
    usage_statistics = UsageStatisticsStore(args.library_root)
    chapter_assembler = ChapterAssembler(book_store)
    summary_manager = SummaryManager(
        book_store,
        GeminiSummaryBackend(
            GeminiSummaryConfig(
                model=args.summary_gemini_model,
                project_id=args.summary_gcp_project,
                location=args.summary_gcp_location,
            )
        ),
        SummaryManagerConfig(
            chapter_summary_target_pages=args.chapter_summary_target_pages,
            book_summary_target_pages=args.book_summary_target_pages,
            language=language_profile.code,
        ),
    )
    nfc_tag_reader = None
    if args.nfc_mode == "gateway":
        nfc_tag_reader = GatewayNFCTagReader(
            NFCGatewayConfig(
                device=args.nfc_device,
                baud=args.nfc_baud,
                timeout=args.nfc_timeout,
            )
        )
    volume_controller = AudioVolumeController(
        AudioVolumeConfig(mixer_control=args.volume_mixer_control)
    )
    controller = RuntimeController(
        monitor=monitor,
        job_manager=job_manager,
        action_callback=_print_action,
        status_callback=lambda message: _print_status(f"runtime: {message}"),
        dummy_capture_job_seconds=args.dummy_job_seconds,
        capture_ocr_config=capture_ocr_config,
        capture_ocr_enabled=args.job_mode == "capture-ocr",
        page_ingest_service=page_ingest_service,
        page_ingest_config=PageIngestRuntimeConfig(
            library_root=args.library_root,
            fallback_tag_id=args.book_tag_id,
        ),
        system_audio_config=_build_system_audio_config(language_profile),
        page_audio_player=PageAudioPlayer(
            config=_build_page_speech_config(args, language_profile),
            status_callback=lambda message: _print_status(f"readout: {message}"),
            volume_provider=volume_controller.current_percent,
        ),
        chapter_assembler=chapter_assembler,
        summary_manager=summary_manager,
        volume_controller=volume_controller,
        nfc_tag_reader=nfc_tag_reader,
        usage_statistics=usage_statistics,
    )

    try:
        if args.job_mode == "capture-ocr":
            cleanup_text = (
                "Debug-Modus: alle technischen Artefakte bleiben erhalten."
                if args.artifact_mode == "debug"
                else f"Produktiv-Modus: Cleanup {args.cleanup_stage} aktiv."
            )
            _print_status(
                "Testmodus: Start / Stop startet bzw. stoppt den echten Capture/OCR-Pfad. "
                f"Page-Ingest speichert unter {args.library_root}; Buch-ID kommt aus {args.nfc_mode}. "
                f"Seitenausgabe verwendet {args.page_tts_backend}. "
                f"{cleanup_text} Dreifachtaste startet den Buch-Loeschdialog. "
                "Andere Eingaben werden nur als Text ausgegeben."
            )
        else:
            _print_status(
                "Testmodus: Start / Stop startet bzw. stoppt einen Dummy-Capture/OCR-Job. "
                "Andere Eingaben werden nur als Text ausgegeben."
            )
        controller.run_forever()
        return 0
    except KeyboardInterrupt:
        controller.stop()
        print("\nBeendet.", flush=True)
        return 0
    except RuntimeError as exc:
        print(f"Fehler: {exc}", file=sys.stderr)
        return 1


if __name__ == "__main__":
    raise SystemExit(main())

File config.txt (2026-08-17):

# For more options and information see
# http://rptl.io/configtxt
# Some settings may impact device functionality. See link above for details

# Uncomment some or all of these to enable the optional hardware interfaces
#dtparam=i2c_arm=on
#dtparam=i2s=on
#dtparam=spi=on

# Enable audio (loads snd_bcm2835)
dtparam=audio=on

# Additional overlays and parameters are documented
# /boot/firmware/overlays/README

# Automatically load overlays for detected DSI displays
display_auto_detect=1

# Automatically load initramfs files, if found
auto_initramfs=1

# Enable DRM VC4 V3D driver
dtoverlay=vc4-kms-v3d
max_framebuffers=2

# Don't have the firmware create an initial video= setting in cmdline.txt.
# Use the kernel's default instead.
disable_fw_kms_setup=1

# Run in 64-bit mode
arm_64bit=1

# Disable compensation for displays with overscan
disable_overscan=1

# Run as fast as firmware / board allows
arm_boost=1

[cm4]
# Enable host mode on the 2711 built-in XHCI USB controller.
# This line should be removed if the legacy DWC2 controller is required
# (e.g. for USB device mode) or if USB support is not required.
otg_mode=1

[cm5]
dtoverlay=dwc2,dr_mode=host

[all]
dtparam=i2s=on
dtoverlay=max98357a

camera_auto_detect=0
dtoverlay=imx519,cam0

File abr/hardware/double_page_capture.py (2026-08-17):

from __future__ import annotations

import argparse
import json
import shutil
import subprocess
import sys
import time
from dataclasses import dataclass
from datetime import datetime, timezone
from pathlib import Path
from typing import Callable

import numpy as np

from abr.hardware.double_page_rectify import apply_rotation_in_place
from abr.hardware.led_control import LEDController
from abr.preprocessing.enhance_for_ocr import enhance_case_dir
from abr.preprocessing.processor import PreprocessorConfig


DEFAULT_OUTPUT_ROOT = Path("captures")
DEFAULT_STILL_COMMAND = "rpicam-still"


@dataclass(slots=True)
class CaptureSlot:
    slot_name: str
    camera_index: int
    remap_path: Path
    rotate_deg: int = 0
    led_channel: str | None = None


@dataclass(slots=True)
class CaptureSessionResult:
    session_dir: Path
    case_dir: Path | None
    ocr_dir: Path | None
    metadata_path: Path


def build_parser() -> argparse.ArgumentParser:
    parser = argparse.ArgumentParser(
        description=(
            "Erfasst eine Buchdoppelseite mit zwei Pi-Kameras, entzerrt beide Bilder "
            "und erzeugt einen left/right-Case-Ordner fuer die bestehende ABR-Pipeline."
        )
    )
    parser.add_argument(
        "--output-root",
        type=Path,
        default=DEFAULT_OUTPUT_ROOT,
        help=f"Zielwurzel fuer Scan-Sessions, Standard: {DEFAULT_OUTPUT_ROOT}",
    )
    parser.add_argument(
        "--session-name",
        help="Optionaler fester Session-Name statt des Zeitstempels.",
    )
    parser.add_argument(
        "--left-camera",
        type=int,
        default=0,
        help="Kameraindex fuer die linke Buchseite, Standard: 0",
    )
    parser.add_argument(
        "--right-camera",
        type=int,
        default=1,
        help="Kameraindex fuer die rechte Buchseite, Standard: 1",
    )
    parser.add_argument(
        "--left-remap",
        type=Path,
        help="Optionale Remap-Datei fuer die linke Seite. Standard: calibration/out/cam<left-camera>_planar.npz",
    )
    parser.add_argument(
        "--right-remap",
        type=Path,
        help="Optionale Remap-Datei fuer die rechte Seite. Standard: calibration/out/cam<right-camera>_planar.npz",
    )
    parser.add_argument(
        "--width",
        type=int,
        help="Optionale Capture-Breite fuer rpicam-still.",
    )
    parser.add_argument(
        "--height",
        type=int,
        help="Optionale Capture-Hoehe fuer rpicam-still.",
    )
    parser.add_argument(
        "--timeout-ms",
        type=int,
        default=1200,
        help="Capture-Timeout fuer rpicam-still in Millisekunden, Standard: 1200",
    )
    parser.add_argument(
        "--jpeg-quality",
        type=int,
        default=95,
        help="JPEG-Qualitaet fuer rpicam-still, Standard: 95",
    )
    parser.add_argument(
        "--shutter-us",
        type=int,
        help=(
            "Optionale manuelle Belichtungszeit fuer beide Kameras in Mikrosekunden. "
            "Ohne Angabe bleibt rpicam-still bei der normalen Automatik."
        ),
    )
    parser.add_argument(
        "--gain",
        type=float,
        help=(
            "Optionaler analoger Gain fuer beide Kameras. "
            "Ohne Angabe bleibt die Gain-Regelung im normalen Automatikpfad."
        ),
    )
    parser.add_argument(
        "--still-command",
        default=DEFAULT_STILL_COMMAND,
        help=f"Capture-Kommando, Standard: {DEFAULT_STILL_COMMAND}",
    )
    parser.add_argument(
        "--python-executable",
        default=sys.executable,
        help="Python fuer die Remap-Anwendung, Standard: aktueller Interpreter",
    )
    parser.add_argument(
        "--raw-only",
        action="store_true",
        help="Nur Rohbilder aufnehmen und keinen Rectify-/Case-Ordner erzeugen.",
    )
    parser.add_argument(
        "--left-rotate",
        type=int,
        default=0,
        choices=[0, 90, 180, 270],
        help="Optionale Nachrotation der linken Seite in Grad, Standard: 0",
    )
    parser.add_argument(
        "--right-rotate",
        type=int,
        default=0,
        choices=[0, 90, 180, 270],
        help="Optionale Nachrotation der rechten Seite in Grad, Standard: 0",
    )
    parser.add_argument(
        "--no-denoise",
        action="store_true",
        help="Deaktiviert das langsame De-Noising in der OCR-Vorverarbeitung.",
    )
    parser.add_argument(
        "--skip-enhance",
        action="store_true",
        help="Nur Capture/Rectify/Case erzeugen und die OCR-Vorverarbeitung spaeter ausfuehren.",
    )
    return parser


def parse_args(argv: list[str] | None = None) -> argparse.Namespace:
    args = build_parser().parse_args(argv)
    if args.width is None and args.height is not None:
        raise SystemExit("--height erfordert auch --width.")
    if args.width is not None and args.height is None:
        raise SystemExit("--width erfordert auch --height.")
    if args.left_camera == args.right_camera:
        raise SystemExit("--left-camera und --right-camera muessen verschieden sein.")
    if not 1 <= args.jpeg_quality <= 100:
        raise SystemExit("--jpeg-quality muss zwischen 1 und 100 liegen.")
    if args.shutter_us is not None and args.shutter_us <= 0:
        raise SystemExit("--shutter-us muss groesser als 0 sein.")
    if args.gain is not None and args.gain <= 0:
        raise SystemExit("--gain muss groesser als 0 sein.")
    if args.timeout_ms < 0:
        raise SystemExit("--timeout-ms darf nicht negativ sein.")
    return args
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

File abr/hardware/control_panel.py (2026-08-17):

from __future__ import annotations

from collections.abc import Sequence
import re
import shutil
import subprocess
from typing import Callable, Protocol


ENCODER_A_PIN = 5
ENCODER_B_PIN = 6

BUTTON_PINS = {
    "encoder_button": 16,
    "start_stop_nfc": 17,
    "book_summary": 22,
    "chapter_summary": 24,
}

PIN_LABELS = {
    ENCODER_A_PIN: "EC11 A",
    ENCODER_B_PIN: "EC11 B",
    BUTTON_PINS["encoder_button"]: "EC11 Taster",
    BUTTON_PINS["start_stop_nfc"]: "Start / Stop / NFC",
    BUTTON_PINS["book_summary"]: "Buch-Zusammenfassung",
    BUTTON_PINS["chapter_summary"]: "Kapitel-/Letzte-Seiten-Zusammenfassung",
}

BUTTON_LABELS = {
    pin: PIN_LABELS[pin]
    for pin in (
        BUTTON_PINS["encoder_button"],
        BUTTON_PINS["start_stop_nfc"],
        BUTTON_PINS["book_summary"],
        BUTTON_PINS["chapter_summary"],
    )
}

CONTROL_PANEL_PINS = [
    ENCODER_A_PIN,
    ENCODER_B_PIN,
    BUTTON_PINS["encoder_button"],
    BUTTON_PINS["start_stop_nfc"],
    BUTTON_PINS["book_summary"],
    BUTTON_PINS["chapter_summary"],
]

_PINCTRL_LINE_RE = re.compile(r"^\s*(?P<pin>\d+)\s*:.*?\b(?P<level>hi|lo)\b", re.IGNORECASE)
_LEVEL_RE = re.compile(r"\b(?P<level>hi|lo)\b", re.IGNORECASE)


class InputGPIO(Protocol):
    def configure_inputs(self, pins: Sequence[int]) -> None: ...

    def read_levels(self, pins: Sequence[int]) -> dict[int, bool]: ...

    def add_edge_callback(self, pin: int, callback: Callable[[int], None]) -> bool: ...

    def remove_edge_callback(self, pin: int) -> None: ...

    def close(self) -> None: ...


def pin_label(pin: int) -> str:
    try:
        return PIN_LABELS[pin]
    except KeyError as exc:
        raise ValueError(f"Unbekannter Control-Panel-Pin: {pin}") from exc


def button_label(pin: int) -> str:
    try:
        return BUTTON_LABELS[pin]
    except KeyError as exc:
        raise ValueError(f"Unbekannter Taster-Pin: {pin}") from exc


def parse_pinctrl_levels(output: str) -> dict[int, bool]:
    levels: dict[int, bool] = {}
    for line in output.splitlines():
        match = _PINCTRL_LINE_RE.search(line)
        if match:
            levels[int(match.group("pin"))] = match.group("level").lower() == "hi"
    return levels


def parse_single_pinctrl_level(output: str) -> bool:
    match = _LEVEL_RE.search(output)
    if not match:
        raise RuntimeError(f"Konnte keinen GPIO-Pegel aus pinctrl-Ausgabe lesen: {output.strip()!r}")
    return match.group("level").lower() == "hi"


class PinctrlInputGPIO:
    def __init__(self, pinctrl_path: str | None = None) -> None:
        self._pinctrl = pinctrl_path or shutil.which("pinctrl")
        if not self._pinctrl:
            raise RuntimeError(
                "Das Kommando 'pinctrl' wurde nicht gefunden. "
                "Dieses Skript ist fuer Raspberry Pi OS auf dem Pi 5 gedacht."
            )
        self._supports_multi_get: bool | None = None

    def _run(self, *args: str) -> subprocess.CompletedProcess[str]:
        return subprocess.run(
            [self._pinctrl, *args],
            check=True,
            text=True,
            capture_output=True,
        )

    def configure_input_pullup(self, pin: int) -> None:
        self._run("set", str(pin), "ip", "pu")

    def configure_inputs(self, pins: Sequence[int]) -> None:
        for pin in pins:
            self.configure_input_pullup(pin)

    def read_level(self, pin: int) -> bool:
        return parse_single_pinctrl_level(self._run("get", str(pin)).stdout)

    def read_levels(self, pins: Sequence[int]) -> dict[int, bool]:
        ordered_pins = list(dict.fromkeys(pins))
        if self._supports_multi_get is not False:
            try:
                output = self._run("get", *(str(pin) for pin in ordered_pins)).stdout
                levels = parse_pinctrl_levels(output)
                if all(pin in levels for pin in ordered_pins):
                    self._supports_multi_get = True
                    return levels
            except subprocess.CalledProcessError:
                self._supports_multi_get = False

        self._supports_multi_get = False
        return {pin: self.read_level(pin) for pin in ordered_pins}

    def add_edge_callback(self, pin: int, callback: Callable[[int], None]) -> bool:
        del pin, callback
        return False

    def remove_edge_callback(self, pin: int) -> None:
        del pin

    def close(self) -> None:
        return None


class RPiGPIOInputGPIO:
    def __init__(self, gpio_module: object | None = None) -> None:
        if gpio_module is None:
            try:
                import RPi.GPIO as gpio_module  # type: ignore[import-not-found]
            except ModuleNotFoundError as exc:
                raise RuntimeError(
                    "Das Python-Modul 'RPi.GPIO' wurde nicht gefunden. "
                    "Auf dem Pi ist dafuer typischerweise das Paket 'rpi-lgpio' noetig."
                ) from exc

        self._gpio = gpio_module
        self._configured_pins: set[int] = set()
        self._edge_callback_pins: set[int] = set()
        self._setmode_done = False

    def _ensure_mode(self) -> None:
        if self._setmode_done:
            return
        self._gpio.setwarnings(False)
        self._gpio.setmode(self._gpio.BCM)
        self._setmode_done = True

    def configure_input_pullup(self, pin: int) -> None:
        self._ensure_mode()
        self._gpio.setup(pin, self._gpio.IN, pull_up_down=self._gpio.PUD_UP)
        self._configured_pins.add(pin)

    def configure_inputs(self, pins: Sequence[int]) -> None:
        for pin in pins:
            self.configure_input_pullup(pin)

    def read_level(self, pin: int) -> bool:
        self._ensure_mode()
        return bool(self._gpio.input(pin))

    def read_levels(self, pins: Sequence[int]) -> dict[int, bool]:
        return {pin: self.read_level(pin) for pin in dict.fromkeys(pins)}

    def add_edge_callback(self, pin: int, callback: Callable[[int], None]) -> bool:
        self._ensure_mode()
        if pin not in self._configured_pins:
            raise RuntimeError(f"GPIO {pin} muss vor der Interrupt-Konfiguration als Eingang gesetzt sein.")
        self._gpio.add_event_detect(pin, self._gpio.BOTH, callback=callback)
        self._edge_callback_pins.add(pin)
        return True

    def remove_edge_callback(self, pin: int) -> None:
        if pin not in self._edge_callback_pins:
            return
        self._gpio.remove_event_detect(pin)
        self._edge_callback_pins.discard(pin)

    def close(self) -> None:
        if not self._configured_pins:
            return
        for pin in tuple(self._edge_callback_pins):
            self.remove_edge_callback(pin)
        self._gpio.cleanup(sorted(self._configured_pins))
        self._configured_pins.clear()
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

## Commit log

2026-08-17 Initial public release
    [LED_bar_long.kicad_pcb, LED_bar_long.kicad_sch, LED_wedge.3mf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]
2026-08-18 Use RapidOCR text boxes for orientation samples
2026-08-27 BOM added
    [BOM.xlsx, bom.csv, designators.csv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]
2026-08-27 BOM pdf added
    [BOM.xlsx]
2026-09-13 readme.md additions
    [BOM.xlsx]
2026-09-21 antenna matching improved
2026-09-29 pn5180 board rev 2.0
    [PN5180_Matching_Smith.sch, bom.csv, bom.xlsx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]
2026-10-03 update design files of front, back, front2, back2, including _dev variants. new camera_block design
    [back.3mf, back.f3d, back.stl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]
